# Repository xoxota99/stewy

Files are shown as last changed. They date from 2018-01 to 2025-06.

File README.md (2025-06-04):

# 6dof-stewduino

Arduino project for a 6DOF, PID-controlled Stewart platform, running on Teensy. Inspired by https://www.youtube.com/watch?v=j4OmVLc_oDw.

## Goal

Teach myself embedded development, using something a little more unique/less trivial than a typical "Blinky" app. This project incorporates:
  * Bi-directional Serial I/O (Command shell)
  * Wiimote nunchuck control (over I2C)
  * Resistive touchscreen (Analog 4-wire)
  * Multiple servos (Digital IO)

## Project Description

A ball bearing sits on the touchscreen, which reports the X/Y coordinates of the weight. The X/Y coordinates are used to generate an "error" value against the current set point, and this error is used in a PID feedback loop to control six servos. The servos drive the angle of the platform in an inverse-kinematic solution, to drive the ball bearing toward the setpoint.

## Serial Command Interface

The project includes a command-line interface over USB serial that allows you to:
  * Calibrate the touchscreen
  * Tune PID parameters
  * Change the current X/Y setpoint
  * Adjust touchscreen filtering and deadband
  * Control individual servos directly
  * Run demo sequences
  * View system information

Available commands include:
  * `help` - Display available commands
  * `set` - Set a single servo angle
  * `moveto` - Move platform to a specific position
  * `calibrate` - Start touchscreen calibration
  * `px`, `py`, `ix`, `iy`, `dx`, `dy` - Set PID parameters
  * `dump` - Display system information
  * `demo` - Run a demonstration sequence

## Touchscreen

The project uses a [4-wire resistive touchscreen](https://tinyurl.com/ybsr2pmk) and the [Adafruit Touchscreen library](https://github.com/adafruit/Touch-Screen-Library) to determine the X/Y coordinates of the ball bearing. The touchscreen driver includes:
  * Calibration routine with EEPROM storage
  * Moving average filter to reduce noise
  * Deadband filter to prevent jitter

## PID Control Loop

The project uses a Proportional/Integral/Derivative (PID) feedback loop to determine the error position between the ball bearing's current position and the setpoint position. This is used to determine the target orientation of the platform, in order to best return the ball to the setpoint position. Features include:
  * Separate PID controllers for X and Y axes
  * Configurable PID parameters via serial commands
  * Safety limits to prevent unstable behavior

## Wiimote Nunchuck Control

The project uses a Wiimote [nunchuck](https://en.wikipedia.org/wiki/Wii_Remote#Nunchuk) to change "modes" and control various aspects of the platform in real time. Mode changes are indicated by the LED blinking. The various modes can be cycled through in order by clicking the C button:

  * 1 blink: **SETPOINT** - The platform will attempt to keep the ball at a given X/Y setpoint. By default, this is in the middle of the plate. **This is the default mode at startup.** In this mode:
    * The joystick can be used to move the setpoint, with the platform correcting the position of the ball in real time.
    * Clicking the Z button (or resetting the Teensy) resets the setpoint to the middle of the plate.
  
  * 2 blinks: **CONTROL** - Direct control of the platform using the joystick. Input from the touchscreen sensor is ignored completely. In this mode:
    * Clicking the Z button cycles between three sub-modes:
      * **PITCH_ROLL** - (default) The joystick controls the pitch/roll of the platform.
      * **HEAVE_YAW** - The joystick controls the up/down and rotation of the platform.
      * **SWAY_SURGE** - The joystick controls the forward/rear and left/right translation of the platform.
  
  * 3 blinks: **CIRCLE** - *(planned)* The setpoint will move in a circular pattern, around the center of the platform.
  
  * 4 blinks: **EIGHT** - *(planned)* Similar to *CIRCLE*, the setpoint will move in a [Lemniscate of Bernoulli](https://en.wikipedia.org/wiki/Lemniscate_of_Bernoulli), centered on the center of the platform.
  
  * 5 blinks: **SQUARE** - *(planned)* The setpoint will be set to the current location of the ball on the plate.

## Project Structure

The project is organized into the following directory structure:

- `include/`: Header files
  - `core/`: Core functionality and common definitions
  - `drivers/`: Hardware driver interfaces
  - `ui/`: User interface related headers
  - `platform/`: Platform-specific code

- `src/`: Source files
  - `core/`: Core functionality implementation (Platform kinematics)
  - `drivers/`: Hardware driver implementations (TouchScreen, Nunchuck)
  - `ui/`: User interface implementations (CommandLine)
  - `platform/`: Platform-specific implementations

- `examples/`: Example applications
  - `BasicMovement/`: Basic platform movement example
  - `TouchscreenCalibration/`: Touchscreen calibration example

- `doc/`: Documentation
  - `TODO.md`: Project tasks and improvements
  - `CAD files/`: CAD designs for the platform

- `lib/`: External libraries

## Technical Details

- **Platform**: [Teensy 3.x](https://www.pjrc.com/store/teensy32.html)
- **Build System**: PlatformIO
- **Servo Control**: Direct via Arduino Servo library
- **Inverse Kinematics**: Optimized algorithm with boundary checking
- **Touchscreen**: 4-wire resistive with filtering and calibration
- **Nunchuck**: I2C communication with mode management

## Building the Project

To build the project, you can use the provided build script:

```bash
./build.sh
```

Or run PlatformIO directly:

```bash
platformio run
```

## Current Status and Future Improvements

The project currently has:
- ✅ Working inverse kinematics with optimized calculations
- ✅ Touchscreen input with filtering and calibration
- ✅ PID control for ball balancing
- ✅ Basic nunchuck control with mode switching
- ✅ Command-line interface for configuration and control
- ✅ Proper resource management and error handling

Planned improvements:
- Complete the CIRCLE, EIGHT, and SQUARE modes
- Improve mechanical design for easier assembly and lower cost
- Enhance power management to prevent brownouts
- Add unit tests and improve code portability
- Implement auto-tuning for PID controllers

See the [TODO.md](doc/TODO.md) file for a complete list of planned improvements and current status.

## Caveats

* The project is built for Teensy 3.x. Other platforms may require modifications.
* The folder structure is designed for PlatformIO and is incompatible with Arduino IDE.
* Servo control is handled directly in main.cpp rather than through a dedicated driver class.

## License

This project is licensed under the GPL-3.0 License - see the LICENSE file for details.

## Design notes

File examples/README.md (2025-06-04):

# Examples Directory

This directory contains example applications and usage demonstrations for the Stewy project. Each example focuses on a specific aspect of the system.

## Available Examples

- `BasicMovement/`: Demonstrates basic platform movement using the Platform class
  - Shows how to initialize the platform and move it to different positions
  - Includes examples of pitch, roll, and combined movements

- `TouchscreenCalibration/`: Demonstrates the touchscreen calibration process
  - Shows how to initialize and calibrate the touchscreen
  - Includes visualization of touchscreen data

## Planned Examples

The following examples are planned for future development:

- Nunchuck control demonstration
- PID tuning examples
- Mode demonstrations (CIRCLE, EIGHT, SQUARE)

## Usage

Each example is a standalone application that can be compiled and uploaded to the Teensy board. To use an example:

1. Open the example directory in PlatformIO
2. Build and upload the example to your Teensy
3. Follow the instructions in the example's comments

Note that some examples may require specific hardware components to be connected (e.g., touchscreen, nunchuck).

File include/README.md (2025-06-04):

# Include Directory

This directory contains all header files for the Stewy project. Header files are organized into subdirectories based on their functionality.

## Directory Structure

- `core/`: Core functionality and common definitions
  - `Config.h`: Project-wide configuration constants and settings
  - `Platform.h`: Stewart platform kinematics and control interface
  - `PlatformGeometry.h`: Geometric constants and calculations for the platform

- `drivers/`: Hardware driver interfaces
  - `TouchScreen.h`: Interface for the touchscreen driver with filtering and calibration
  - `Nunchuck.h`: Interface for the Wii Nunchuck controller with mode management

- `ui/`: User interface related headers
  - `CommandLine.h`: Serial command interface for controlling the platform

- `platform/`: Platform-specific code
  - `TeensyHardware.h`: Teensy-specific hardware abstractions and utilities

## Usage Guidelines

1. Use relative includes with proper paths (e.g., `#include "core/Config.h"`)
2. Keep header files minimal and focused on a single responsibility
3. Use forward declarations when possible to minimize dependencies
4. Document all public interfaces with Doxygen-style comments
5. Include appropriate copyright and license information in each file

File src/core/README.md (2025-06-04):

# Core Directory

This directory contains the core functionality of the Stewy project. These components form the foundation of the system and are not tied to specific hardware implementations.

## Contents

- `Platform.cpp`: Implementation of the Stewart platform kinematics and control
  - Implements inverse kinematics to calculate servo angles from desired platform position
  - Provides methods for moving the platform to specific positions and orientations
  - Includes boundary checking and error handling for movement parameters

## Key Features

### Inverse Kinematics

The Platform class implements an optimized inverse kinematics algorithm that:
- Calculates servo angles based on desired platform position and orientation
- Supports 6 degrees of freedom (sway, surge, heave, pitch, roll, yaw)
- Includes boundary checking to prevent impossible movements
- Optimizes trigonometric calculations for better performance
- Supports an enhanced IK algorithm with adjustable rotation point

### Platform Control

The Platform class provides methods for:
- Moving the platform to a specific position and orientation
- Moving the platform to a home position
- Simplified control of just pitch and roll
- Getting current platform state

## Architecture

The core components follow these design principles:

1. Hardware independence: Core functionality doesn't depend on specific hardware
2. Clear separation of concerns: Platform kinematics are separate from hardware control
3. Robust error handling: All methods include parameter validation and error reporting
4. Efficient implementation: Optimized calculations for embedded systems

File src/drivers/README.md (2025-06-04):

# Drivers Directory

This directory contains hardware driver implementations for the Stewy project. Each driver provides an interface to a specific hardware component.

## Contents

- `TouchScreen.cpp`: Implementation of the touchscreen driver for detecting ball position
- `Nunchuck.cpp`: Implementation of the Wii Nunchuck controller driver for user input

## Architecture

The drivers in this directory follow a consistent pattern:
- Each driver has a corresponding header file in the `include/drivers/` directory
- Drivers handle hardware initialization, data processing, and provide a clean interface to the rest of the application
- The touchscreen driver includes filtering, calibration, and PID control functionality
- The nunchuck driver handles button events, mode management, and joystick input processing

## Note on Servo Control

Servo control is handled directly in `main.cpp` using the standard Arduino Servo library rather than through a dedicated driver class. This approach was chosen because:
1. The Arduino Servo library already provides a clean interface
2. Servo control in this project is straightforward
3. Servos are tightly integrated with the Platform class's inverse kinematics

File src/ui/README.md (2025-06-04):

# UI Directory

This directory contains user interface components for the Stewy project. These components handle user input and provide feedback to the user.

## Contents

- `CommandLine.cpp`: Implementation of the command-line interface
  - Processes commands from the serial interface
  - Provides a set of commands for controlling and configuring the platform
  - Uses the GeekFactory Shell Library for command parsing and execution

## Features

The command-line interface provides the following functionality:

- Direct servo control (`set`, `mset`, `setall`, `msetall`)
- Platform movement control (`moveto`, `home`)
- System information display (`dump`)
- PID controller tuning (`px`, `py`, `ix`, `iy`, `dx`, `dy`)
- Touchscreen calibration (`calibrate`)
- Log level control (`log`)
- Demo sequence execution (`demo`)
- System reset (`reset`)

## Architecture

The UI components follow these design principles:

1. Separation of concerns: UI components don't directly control hardware
2. Command handlers are implemented as static methods
3. The UI maintains references to other components (touchscreen, nunchuck) but doesn't own them
4. Error handling includes parameter validation and user feedback

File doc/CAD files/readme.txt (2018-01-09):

The layout for base_bottom and base_top are designed for the Hitec HS-5625MG servo.

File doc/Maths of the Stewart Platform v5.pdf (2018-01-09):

## The Mathematics of the Stewart Platform

The Stewart Platform consists of 2 rigid frames connected by 6 variable length legs.

The Base is considered to be the reference frame work, with orthogonal axes x, y, z.

The Platform has its own orthogonal coordinates x’, y’, z’.

The Platform has 6 degrees of freedom with respect to the Base

The origin of the Platform coordinates can be defined by 3 translational displacements with respect to the Base, one for each axis.

Three angular displacements then define the orientation of the platform with respect to the Base. A set of Euler angles are used in the following sequence:

1. Rotate an angle ψ (yaw) around the z-axis
2. Rotate an angle θ (pitch) around the y-axis
3. Rotate an angle (roll) around the x-axis

If we consider the first rotation ψ (yaw) around the z-axis:

P = i’x’ + j’y’ + k’z’ = ix + jy + kz

x = OA – BC

= x’cos ψ – y’sin ψ

y = AB + PC

= x’sin ψ + y’cos ψ

z = z’

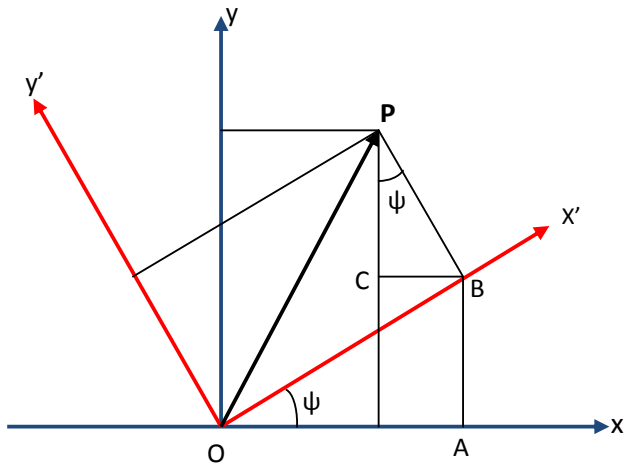
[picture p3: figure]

We define the rotation matrix | where

=

and | =

Similarly If we consider the second rotation θ (pitch) around the y-axis we can show

=

,

And for the third rotation (roll) around the x-axis:

=

The full rotation matrix of the Platform relative to the Base is then given by:

=

=

=

=

- (1)

Now consider a Stewart Platform.

For the

leg:

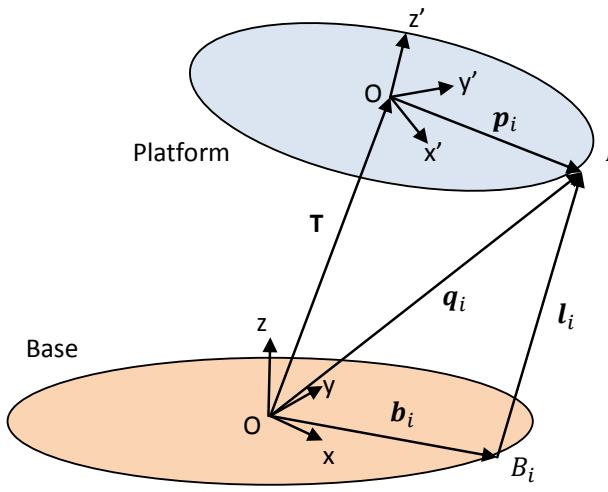
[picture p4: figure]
Platform; Base

The coordinates | of the anchor point | with respect to the Base reference framework are
given by the equation

= T +

- (2)

Where T is the translation vector, giving the positional linear displacement of the origin of the Platform frame with respect to the Base reference framework, and

is the vector defining the coordinates of the anchor point with respect to the Platform framework.

Similarly the length of the

leg is given by

| = T +

- (3)
| where is the vector
defining the coordinates of the lower anchor point
| . These 6 equations give the lengths
of the 6 legs to achieve the desired position and attitude of the platform.

When considering the Forward Kinematics, this expression represents 18 simultaneous non-linear equations in the 6 unknowns representing the position and attitude of the platform. Much work has been done on finding the solutions to these equations; in the general case there are 40 possible solutions, although in practice many of these solutions would not be practical.

If the leg lengths are achieved via rotational servos, rather than linear servos, a further calculation is required to determine the angle of rotation of the servo. Each servo / leg combination can be represented as follows:

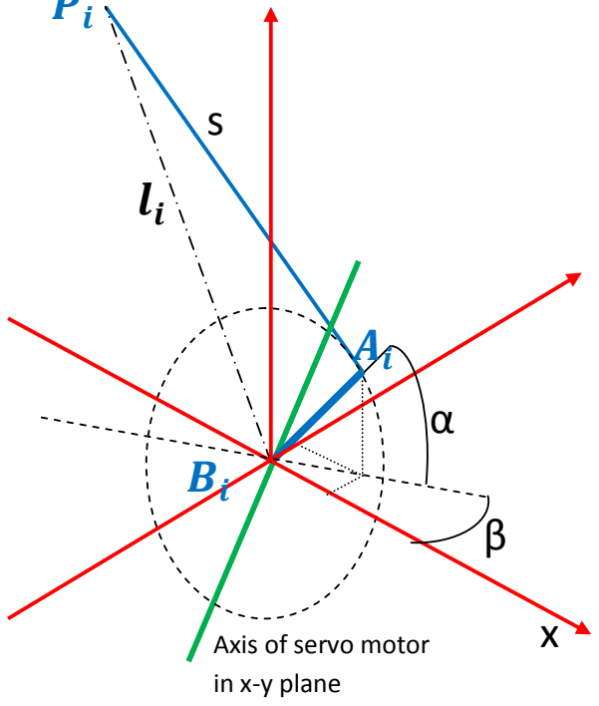
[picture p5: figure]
Axis of servo motor in x-y plane

y

z

Where: a = length of the servo operating arm

are the points of the arm/leg joint on the

servo with coordinates

=

in the base framework.

are the points of rotation of the servo arms with the coordinates

=

in the base framework.

are the points the joints between the operating rods and the platform,

with coordinates | =

in the platform framework

S = length of operating leg

= length of the
leg as calculated from

= T +

α = angle of servo operating arm from horizontal

β = angle of servo arm plane relative to the x-axis. Note that the shaft axis lies in the x-y plane where z = 0

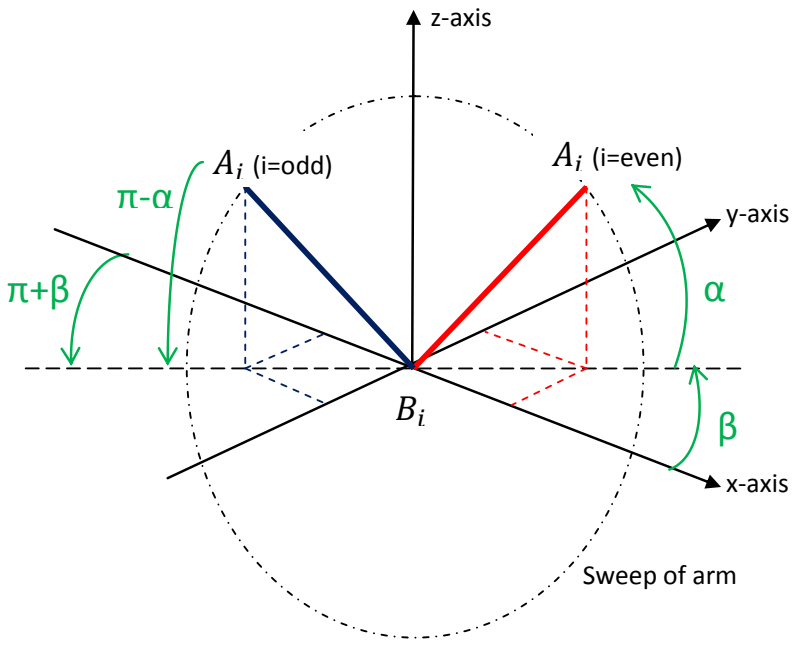
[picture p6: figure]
z-axis; y-axis; x-axis; Sweep of arm; (i=even); (i=odd)

Point is constrained to be on the servo arm, but the arrangement of the servos means that the odd and even arms are a reflection of each other. So for the even legs we have:

= a | , and | - (4)
= a | , and | - (5)

= a | - (6)

And for the odd legs we have:

= a | , and
= a | , and

= a

But | = | , and | =
And | = | , and | =

Substituting these values into the equations for the odd legs, we get the same equations as (4), (5), and (6) for the even legs.

By Pythagoras we also have:

=

+

+

=

+

- 2
- (7)

=

+

+

=

+

- 2 | - (8)

=

+

+

=

+

- 2

And substituting from equations (7) & (8)

=

+ 2 | +

+
2
- 2

re-arranging gives

= 2

+ 2 | + 2 | + 2 | –
2
And substituting for | , | , | from equations (4), (5) & (6) then gives

= 2

+ 2

+
2

+ 2

2

= 2

+ 2 | + 2 | - 2

+
2a | + 2 | - 2
+ 2a | + 2 | -
2

Which reduces to

= 2a | 2 | + 2a
= 2a | 2a

Which is an equation of the form:-

L =

Using the Trig identity for the sum of sine waves

where

and

We therefore have another sine function of α with a phase shift δ

L = | where | δ =
Therefore | =
And | α =

- (9)

where L =

M = 2a

N = 2a

We now have sufficient information to calculate the lengths of the effective “legs”, and the associated angle of the servo arms, for the reverse kinematics for the platform. But to design and implement the hexapod platform we need to define a few constants in order to define the range of movement.

1) We need to define the “home” position of the platform. By definition this will be where the platform is at a height above the base framework, and there being no other translational or rotational movement.

i.e.

= T +

=

=

Similarly we will define the “home” position where the servo arms and rods are at right angles to each other.

i.e.

=

Giving

- (10)

and since the platform is constructed symmetrically around the z-axis, this equation will give the same result for any leg.

2) We can also calculate the angle of the servo arm at the Home position.

Using the equation

= T +

And remembering the symmetrical construction of the platform. The length of the legs in the “home” position is given by

- (11)

And the angle of the servo arm in the “home” position can be given by equation (9). Since we have symmetry, we can look at leg 2 only, where β = 0°.

=

- (12)

where =

= 2

| = 2a
| = 2a
| = 2a

The servos are mounted so that their mid point is close to the “home” position, and we will restrict their movement to ± 45°. The servos are controlled by a pulse whose duration defines the angle of the arm.

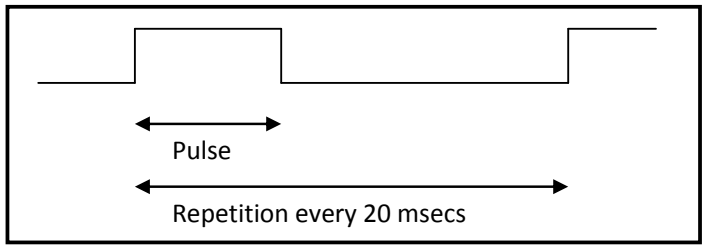
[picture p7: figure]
Pulse; Repetition every 20 msecs

The servos used have the specification:

Neutral position (“home”) is nominally 1500µsecs

Rotation clockwise for increasing pulse width

Pulse width change for 45° is 400 µsecs giving a servo rate,

r =

=

µsecs / radian

From the above, the pulse widths

for each of the servos can be obtained by the equations:

for even i and | -(13)
for odd i | - (14)

Where

is the actual pulse width required to hold the | servo in the “home”
position. This is nominally 1500µsecs, but can be adjusted to compensate for differences in actual assembly.

## Controlling the Stewart Platform using RC Servos

The platform is constructed with symmetry round the z-axes, but the odd and even servos are mounted in opposition.

The circuitry used to control the platform is based on a PICAXE microcontroller with attached maths co-processor (floating point) and attached servo motor controller.

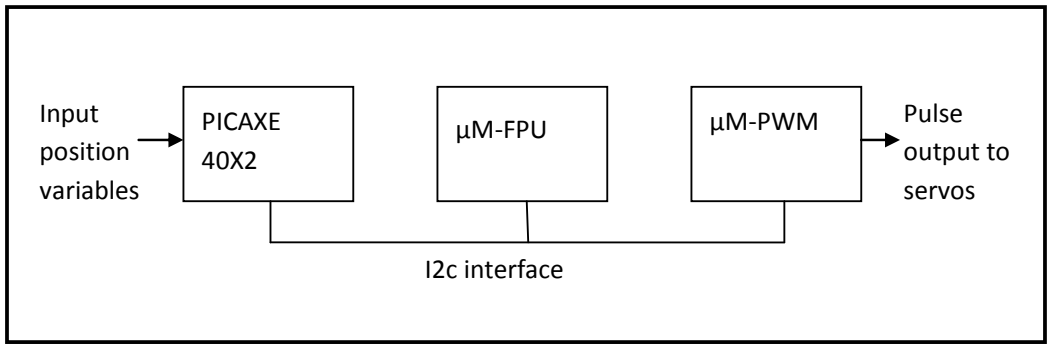
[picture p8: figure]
PICAXE 40X2; µM-FPU; µM-PWM; I2c interface; Input position variables; Pulse output to servos

The sequence of events is as follows:

1) Input the positional information for the platform,

s, a,

. These are all
constants from the build of the platform.
2) Input the constants for the servo motors,

and r
3) Calculate the values of | from equation (10), and | from equation (12)
4) Input the variables for (x, y, z, ψ, θ, φ) for the required platform position
5) Calculate the rotational matrix

from equation (1)
6) Calculate the effective leg lengths
from equations (3)
7) Calculate the angles

required for each servo from equation (9)
8) Calculate the pulse widths

required for each servo from equations (13) & (14)
9) Output the values of

to the µM-PWM to drive the servos
10) Return to step 4) to repeat the process.

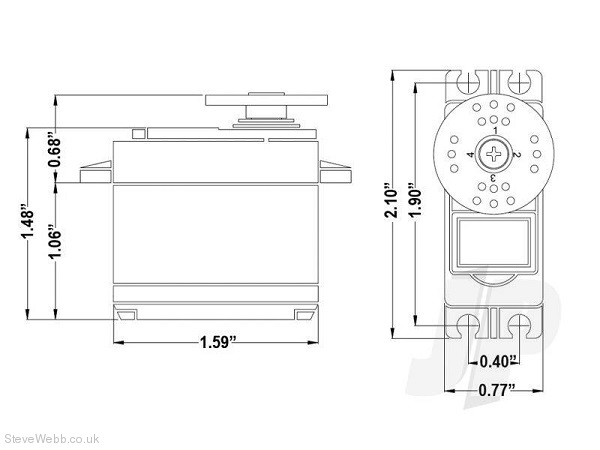
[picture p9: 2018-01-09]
doc/hitec-hs5625d_a.jpg

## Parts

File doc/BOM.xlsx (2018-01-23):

Part | Qty | Unit cost | Total cost | Link
Hitec RCD HS-5625MG Digital High Speed Metal Gear Servo | 6 | $39.00 | $234.00 | https://www.amazon.com/dp/B0006O3XKO
Laser-cut acrylic parts | 1 | $69.00 | $69.00 | https://www.ponoko.com/design-your-own/products/stewduino-clear-14641
4-Wire resistive touchscreen, 12.1" | 1 | $66.57 | $66.57 | https://www.digikey.com/product-detail/en/nkk-switches/FTAS00-12.1AN-4/360-3520-ND/6823699
Teensy 3.2 | 1 | $24.44 | $24.44 | https://www.amazon.com/dp/B015M3K5NG
BEC / regulator | 1 | $19.99 | $19.99 | https://www.amazon.com/dp/B000MXAR12
Turnigy nano-tech 2000mAh 2S1P 20~40C Lipo Receiver Pack | 1 | $12.47 | $12.47 | https://hobbyking.com/en_us/turnigy-nano-tech-2000mah-2s1p-20-40c-lipo-receiver-pack.html
Servo power board | 1 | $9.99 | $9.99 | https://www.amazon.com/dp/B019EH6HYW
control rod ends (6-pack) | 1 | $8.98 | $8.98 | https://www.amazon.com/dp/B075J9WJR7
control rods (20-pack) | 1 | $8.55 | $8.55 | https://www.amazon.com/dp/B00OK6DT76
mounting tape | 1 | $4.49 | $4.49 | https://www.amazon.com/dp/B004E3PMKM
Hardware: M3x10 button-head hex screws | 10 |  | $0.00 | https://www.mcmaster.com/#91239a115
Hardware: M3x12 button-head hex screws | 6 |  | $0.00 | https://www.mcmaster.com/#91239a117
Hardware: M3x16 Counter-sunk hex screws | 4 |  | $0.00 | https://www.mcmaster.com/#91239a120
Hardware: M2x6 socket-head hex screws | 4 |  | $0.00 | https://www.mcmaster.com/#91290a013
0.25" double-sided tape | 1 | $7.99 | $7.99 | https://www.amazon.com/dp/B01MYUFTQO
Tools required:
 | Soldering Iron
 | 1.5mm hex driver |  |  | https://www.amazon.com/dp/B00OCO9178
 | 2.0mm hex driver |  |  | https://www.amazon.com/dp/B00OCO9178
 | drill
 | M2 tapping bit |  |  | https://www.amazon.com/dp/B078H9MTHW
 | countersink bit |  |  | https://www.amazon.com/dp/B01G84OJLC
 | M3 cutting die |  |  | https://www.amazon.com/dp/B005CL47A6
 | hookup wire |  |  | https://www.amazon.com/dp/B008MOLG04
* Note: Links are provided for convenience only. I do not endorse any of these products. Use at own risk.

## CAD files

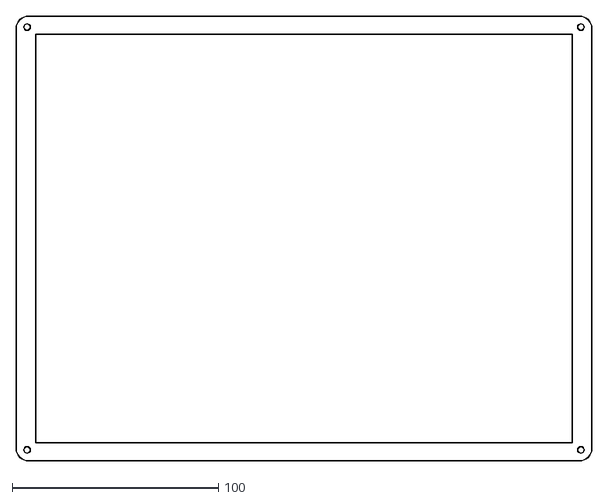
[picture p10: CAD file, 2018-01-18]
doc/CAD files/DXF/ts_platform_over.dxf
279.4 x 215.9

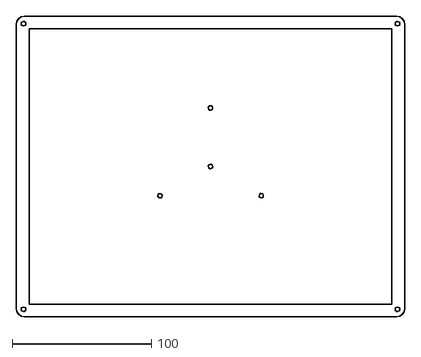
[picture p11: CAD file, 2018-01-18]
doc/CAD files/DXF/ts_platform_under.dxf
279.4 x 215.9

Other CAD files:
doc/CAD files/DXF/base_top.dxf
doc/CAD files/DXF/platform_large.dxf
doc/CAD files/DXF/base_bottom.dxf
doc/CAD files/DXF/platform_small.dxf

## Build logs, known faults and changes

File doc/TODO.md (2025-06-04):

# Stewy Project TODO List

This document tracks improvements and tasks for the Stewy project. Check off items as they are completed.

## 1. Code Quality Improvements

- [x] Add Documentation:
  - [x] Add basic Doxygen-style documentation to class and function headers
  - [x] Complete documentation for all functions with parameters, return values, and behavior

- [ ] Implement Unit Tests:
  - [ ] Create a testing framework for the platform's inverse kinematics
  - [ ] Add tests for the PID controller functionality
  - [ ] Test edge cases for servo movement limits

- [ ] Code Organization:
  - [x] Organize code into proper directory structure with include/ and src/ folders
  - [ ] Further refactor main.cpp into smaller, more focused modules
  - [ ] Create separate classes for different functionalities (e.g., ServoController)

- [ ] Error Handling:
  - [ ] Add more robust error handling throughout the codebase
  - [ ] Implement a proper error reporting system instead of just logging

- [ ] Configuration Management:
  - [x] Use EEPROM to store calibration values
  - [ ] Move more hardcoded values from config.h to a configuration file that can be loaded at runtime

## 2. Feature Implementations

- [ ] Complete Planned Features:
  - [ ] Implement the "coming soon" features mentioned in the README:
    - [ ] CIRCLE mode
    - [ ] EIGHT mode
    - [ ] SQUARE mode
  - [ ] Add the ability to save and load different configurations

- [x] Calibration Improvements:
  - [x] Create an automated calibration routine for the touchscreen
  - [ ] Implement a servo calibration procedure to fine-tune the SERVO_TRIM values

- [ ] User Interface:
  - [x] Implement basic command line interface
  - [ ] Develop a more user-friendly serial command interface
  - [ ] Add a web interface using ESP8266/ESP32 for remote control and monitoring

## 3. Hardware Design Improvements

- [ ] Power Management:
  - [ ] Implement the power management improvements mentioned in the README
  - [ ] Add detection for USB vs. battery power and adjust servo behavior accordingly
  - [ ] Consider adding a separate power supply for the servos

- [ ] Mechanical Design:
  - [ ] Redesign the platform to use a single thickness of material as suggested in the README
  - [ ] Break up the upper ring into smaller pieces for more cost-effective manufacturing
  - [ ] Design a more universal mounting system for different servo types

## 4. Performance Optimizations

- [ ] PID Controller Tuning:
  - [x] Implement configurable PID parameters
  - [ ] Implement auto-tuning for the PID controllers
  - [ ] Add more sophisticated filtering for the touchscreen input

- [x] Inverse Kinematics:
  - [x] Optimize the IK algorithm as mentioned in the README
  - [x] Implement the mathematical improvements for better range of movement
  - [x] Add boundary checking for all movement parameters

- [ ] Memory Usage:
  - [ ] Optimize memory usage, especially for the Teensy platform
  - [ ] Consider using fixed-point math instead of floating-point for performance

## 5. Build and Deployment

- [ ] Cross-Platform Compatibility:
  - [ ] Make the code more portable across different Arduino platforms
  - [ ] Replace Teensy-specific code (like Serial.printf) with more portable alternatives

- [ ] Continuous Integration:
  - [x] Add basic Travis CI configuration
  - [ ] Set up a proper CI/CD pipeline with automated testing

- [ ] Documentation:
  - [ ] Create better user documentation with setup instructions
  - [ ] Add diagrams and illustrations for assembly

## 6. Specific Technical Improvements

- [x] Platform.cpp:
  - [x] Optimize the inverse kinematics calculations
  - [x] Add boundary checking for all movement parameters
  - [x] Implement enhanced IK algorithm with adjustable rotation point

- [x] Touchscreen Handling:
  - [x] Implement filtering for the touchscreen input
  - [x] Add calibration routines for the touchscreen
  - [x] Implement deadzone filter to avoid jitter

- [ ] Servo Control:
  - [x] Add acceleration/deceleration to servo movements for smoother operation
  - [ ] Implement a safety system to prevent servo overheating

- [x] Nunchuck Interface:
  - [x] Implement basic mode switching and control
  - [ ] Improve the responsiveness of the nunchuck controls
  - [ ] Complete implementation of all planned modes

## 7. Logical Errors to Fix

- [x] **PID Controller Input/Output Handling**
  - [x] Review how PID values are updated and ensure proper input/output flow
  - [x] Add validation for PID parameters to prevent unstable behavior

- [x] **Touchscreen Calibration Persistence**
  - [x] Store calibration data in EEPROM
  - [x] Add validation for EEPROM calibration data
  - [x] Implement fallback defaults if calibration data is corrupted

- [ ] **Error Handling for Missing Hardware**
  - [x] Add detection for nunchuck connection
  - [ ] Implement more graceful handling for connected but non-responsive hardware
  - [ ] Implement timeout mechanisms for hardware communication

- [x] **Resource Management**
  - [x] Add proper cleanup for objects created with `new`
  - [ ] Consider using smart pointers or RAII patterns for better resource management

- [ ] **Concurrent Access to Servo Values**
  - [ ] Implement a synchronization mechanism for the servoValues array
  - [ ] Create a priority system for different components updating servo positions

- [x] **Timing Issues**
  - [x] Add timing control to the main loop for consistent execution
  - [x] Ensure PID loops run at consistent intervals for proper control

- [ ] **Initialization Order Dependencies**
  - [x] Implement proper initialization sequence
  - [ ] Add more explicit checks to ensure components are initialized before use

- [ ] **Lack of Bounds Checking**
  - [x] Add bounds checking for platform movement parameters
  - [ ] Add explicit bounds checking for all array accesses
  - [ ] Implement safe accessor methods for critical data structures

- [ ] **Incomplete Implementation of Planned Features**
  - [ ] Complete or disable advertised features that aren't fully implemented
  - [ ] Add clear status indicators for features in development

- [ ] **Potential Floating Point Precision Issues**
  - [x] Optimize floating point calculations in inverse kinematics
  - [ ] Consider fixed-point alternatives for critical calculations

- [ ] **Inconsistent Error Handling**
  - [ ] Standardize error handling approach across the codebase
  - [ ] Ensure all return values are properly checked

- [ ] **Potential for Servo Binding**
  - [ ] Implement protection against servo binding conditions
  - [ ] Add current monitoring if hardware supports it
  - [ ] Create safe recovery procedures for high-current states

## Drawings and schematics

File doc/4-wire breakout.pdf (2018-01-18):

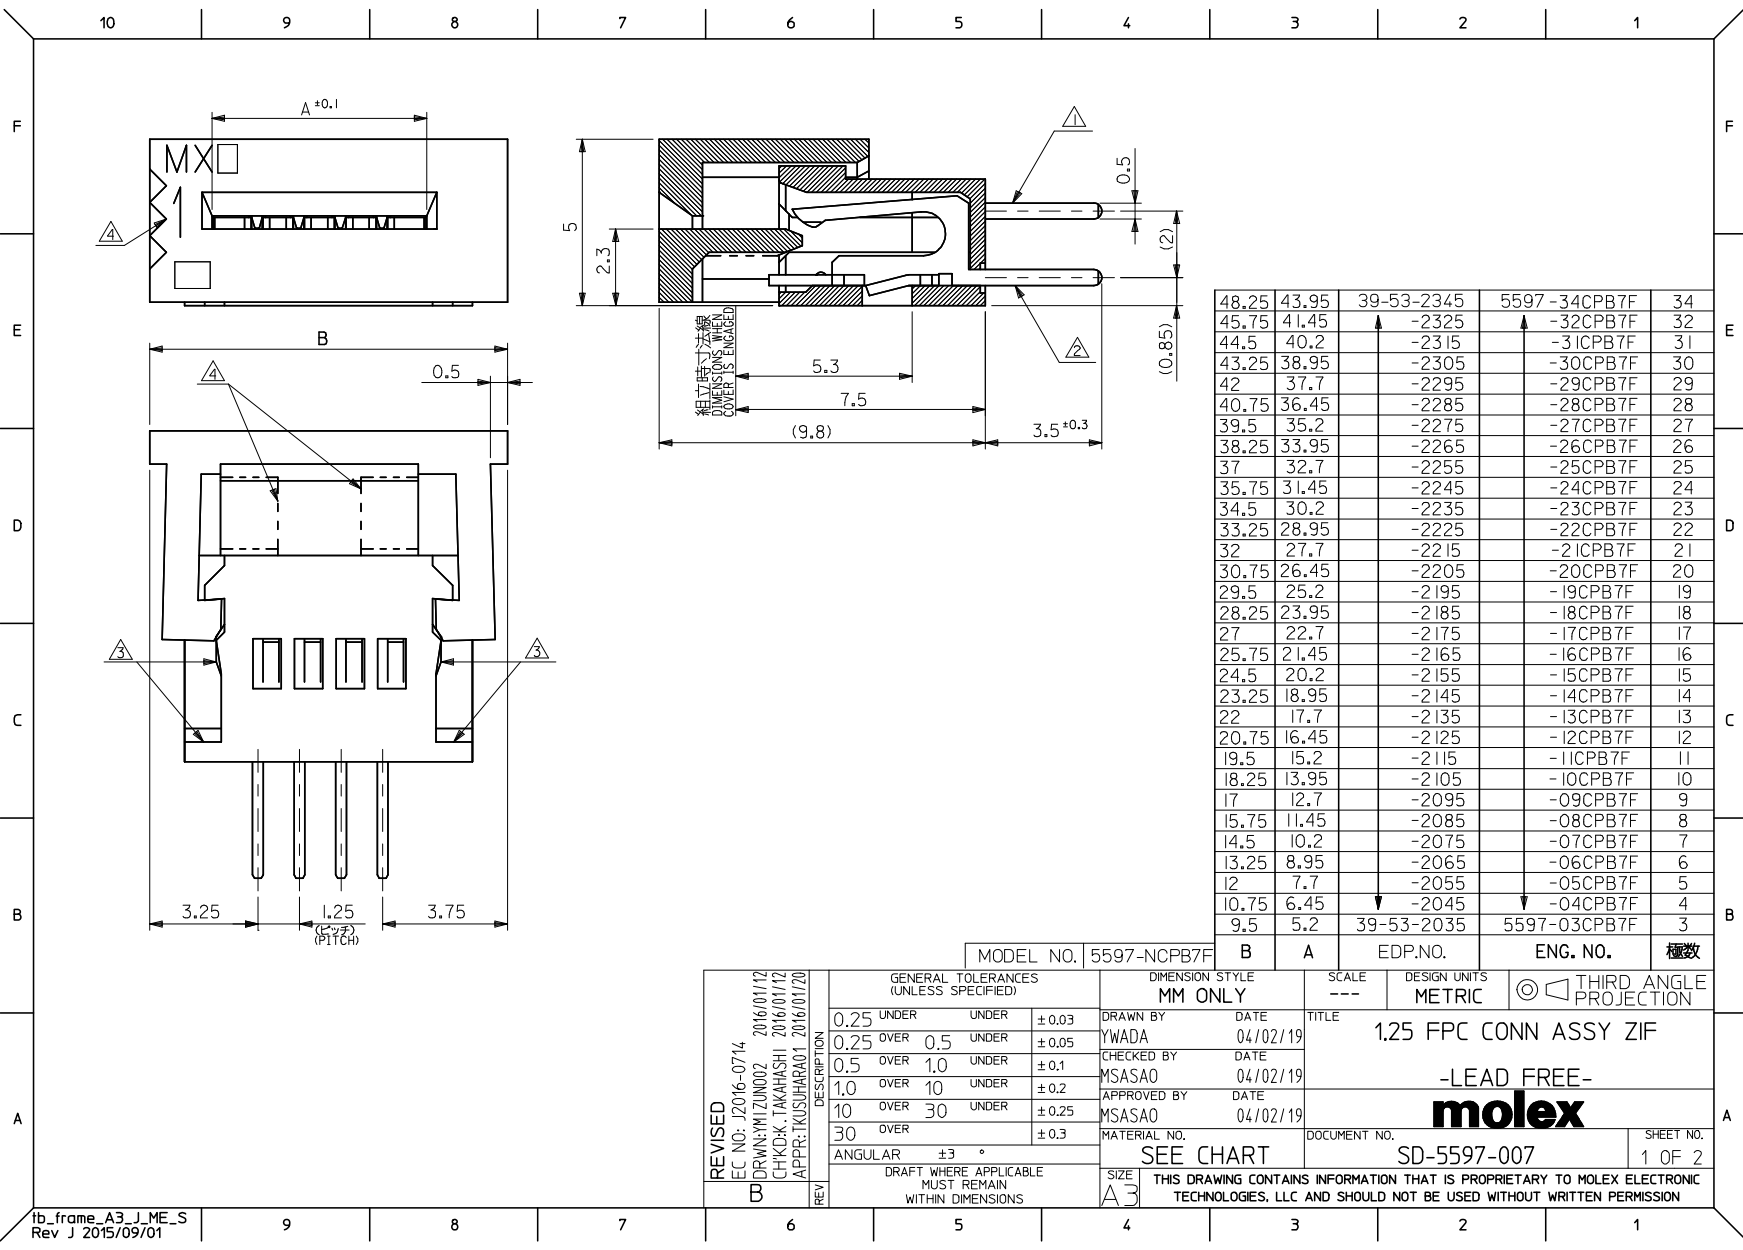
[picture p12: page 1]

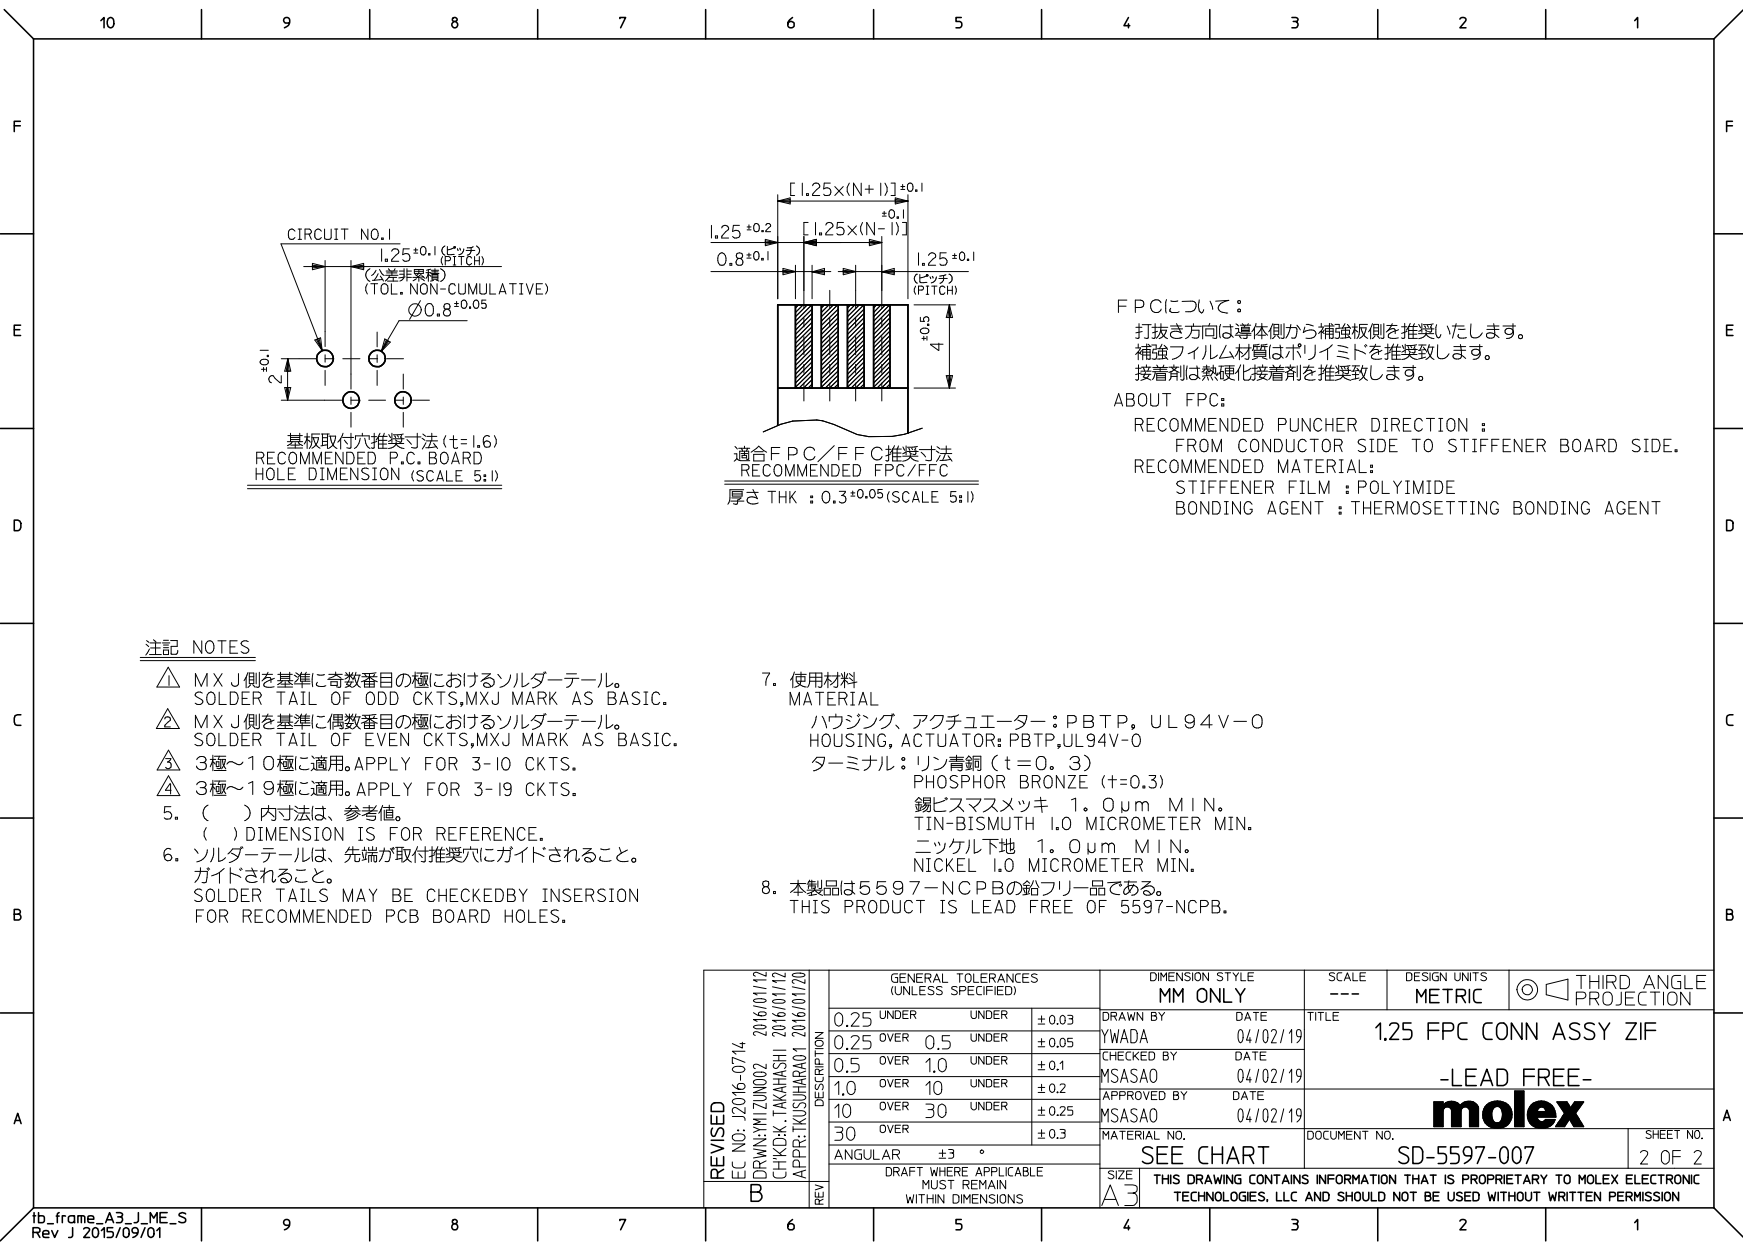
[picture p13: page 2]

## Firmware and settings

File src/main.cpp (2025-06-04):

/**
 * @file main.cpp
 * @brief Main entry point for the Stewart platform project
 *
 * This file contains the setup and loop functions required by Arduino/Teensy.
 *
 * @author Philippe Desrosiers
 * @copyright Copyright (C) 2018 Philippe Desrosiers
 * @license GPL-3.0
 *
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
 * You should have received a copy of the GNU General Public License
 * along with this program.  If not, see <https://www.gnu.org/licenses/>.
 */

#include <Arduino.h>
#include <ArduinoLog.h>
#include <Servo.h>
#include "core/Config.h"
#include "core/Platform.h"
#ifdef ENABLE_TOUCHSCREEN
#include "drivers/TouchScreen.h"
#endif

#ifdef ENABLE_NUNCHUCK
#include "drivers/Nunchuck.h"
#endif

#ifdef ENABLE_SERIAL_COMMANDS
#include "ui/CommandLine.h"
#endif

// this is the magic trick for printf to support float
asm(".global _printf_float");
// this is the magic trick for scanf to support float
asm(".global _scanf_float");

// Define the namespace for the Stewart platform
using namespace stewy;

// Create platform object
core::Platform *platform;

#ifdef ENABLE_SERVOS
// Create servo objects
Servo servos[6];
#endif

// Servo setpoints in degrees
float servoValues[6];

// Current actual servo positions (for acceleration/deceleration)
float currentServoPositions[6];

// Current servo velocities (for acceleration/deceleration)
float servoVelocities[6];

// Create driver objects
drivers::TouchScreenDriver *touchscreen;
drivers::NunchuckDriver *nunchuck;

// Create UI objects
ui::CommandLine *commandLine;

// Function to convert angle to microseconds
float toMicroseconds(int angle)
{
  return map(angle, SERVO_MIN_ANGLE, SERVO_MAX_ANGLE, SERVO_MIN_US, SERVO_MAX_US);
}

// Update servo positions
void updateServos()
{
  for (int i = 0; i < 6; i++)
  {
    float targetPosition = servoValues[i];
    float currentPosition = currentServoPositions[i];

#ifdef SERVO_ACCELERATION_ENABLED

    // Calculate the distance to the target
    float distance = targetPosition - currentPosition;

    if (abs(distance) > 0.01f) // Small threshold to avoid tiny movements
    {
      // Determine the direction of movement
      float direction = (distance > 0) ? 1.0f : -1.0f;

      // Calculate the desired velocity based on distance
      float desiredVelocity = direction * min(abs(distance), SERVO_MAX_SPEED);

      // Apply acceleration/deceleration
      if (servoVelocities[i] < desiredVelocity)
      {
        // Accelerate
        servoVelocities[i] = min(servoVelocities[i] + SERVO_ACCELERATION, desiredVelocity);
      }
      else if (servoVelocities[i] > desiredVelocity)
      {
        // Decelerate
        servoVelocities[i] = max(servoVelocities[i] - SERVO_ACCELERATION, desiredVelocity);
      }

      // Apply velocity to position
      currentPosition += servoVelocities[i];

      // Check if we've reached or overshot the target
      if ((direction > 0 && currentPosition >= targetPosition) ||
          (direction < 0 && currentPosition <= targetPosition))
      {
        currentPosition = targetPosition;
        servoVelocities[i] = 0;
      }
    }
    else
    {
      // We're at the target, ensure velocity is zero
      servoVelocities[i] = 0;
    }

    // Update the current position
    currentServoPositions[i] = currentPosition;
#else

    // No acceleration/deceleration, just use the target position
    currentPosition = targetPosition;
    currentServoPositions[i] = currentPosition;
#endif // SERVO_ACCELERATION_ENABLED

    // Apply reverse if needed
    float val = currentPosition;
    if (core::SERVO_REVERSE[i])
    {
      val = SERVO_MIN_ANGLE + (SERVO_MAX_ANGLE - val);
    }

    // Convert to microseconds and apply trim
    val = toMicroseconds(val) + core::SERVO_TRIM[i];

// Write to servo
#ifdef ENABLE_SERVOS
    servos[i].writeMicroseconds(constrain(val, SERVO_MIN_US, SERVO_MAX_US));
#endif
  }
}

void setup()
{
  // Initialize serial communication
  Serial.begin(115200);
  delay(100);

  Log.begin(LOG_LEVEL, &Serial);
  Log.info("Stewy Platform Starting...");
  Log.info("Built %s, %s", __DATE__, __TIME__);

  // Initialize platform
  platform = new core::Platform(SERVO_MIN_ANGLE, SERVO_MAX_ANGLE);

  // Initialize servo position and velocity arrays
  for (int i = 0; i < 6; i++)
  {
    currentServoPositions[i] = core::SERVO_MID_ANGLE;
    servoVelocities[i] = 0.0f;
  }

// Initialize servos
#ifdef ENABLE_SERVOS
  Log.info("Initializing servos...");
  for (int i = 0; i < 6; i++)
  {
    servos[i].attach(core::SERVO_PINS[i]);
  }
#else
  Log.info("Servo control is DISABLED");
#endif

// Initialize touchscreen
#ifdef ENABLE_TOUCHSCREEN
  Log.info("Initializing touchscreen...");
  touchscreen = new drivers::TouchScreenDriver(XP, YP, XM, YM, TS_OHMS);
  touchscreen->init();
#else
  Log.info("Touchscreen support is DISABLED");
#endif

// Initialize nunchuck
#ifdef ENABLE_NUNCHUCK
  Log.info("Initializing nunchuck...");
  nunchuck = new drivers::NunchuckDriver();
  nunchuck->init();
#else
  Log.info("Nunchuck support is DISABLED");
#endif

// Initialize command line
#ifdef ENABLE_SERIAL_COMMANDS
  Log.info("Initializing command line interface...");
  commandLine = new ui::CommandLine(touchscreen, nunchuck, servoValues);
  commandLine->init();
#else
  Log.info("Command line interface is DISABLED");
#endif

  // Do a litlle initialization sequence
  Log.info("Sweeping servos to ensure they are working...");
  for (int pos = SERVO_MIN_ANGLE; pos < core::SERVO_MID_ANGLE; pos += 4)
  {
    for (int i = 0; i < 6; i++)
    {
      servoValues[i] = pos;
    }

    updateServos();
    delay(10);
  }

  // Move to home position
  platform->home(servoValues);
  updateServos();

  Log.info("Initialization complete");
}

void loop()
{
  // Record the start time of this loop iteration
  unsigned long loopStartTime = millis();

// Process command line
#ifdef ENABLE_SERIAL_COMMANDS
  commandLine->process();
#endif

// Process nunchuck input
#ifdef ENABLE_NUNCHUCK
  core::xy_coordf setpoint = nunchuck->process(servoValues);

  // Process the Blinker to handle LED blinking
  stewy::drivers::modeBlinker.loop();
#else
  core::xy_coordf setpoint = core::DEFAULT_SETPOINT;
#endif

// Process touchscreen
#ifdef ENABLE_TOUCHSCREEN
  touchscreen->process(setpoint.x, setpoint.y, servoValues);
#endif

  // Update servos
  updateServos();

  // Calculate how long this iteration took
  unsigned long loopDuration = millis() - loopStartTime;

  // If we completed faster than our target interval, delay the remaining time
  if (loopDuration < MAIN_LOOP_INTERVAL_MS)
  {
    delay(MAIN_LOOP_INTERVAL_MS - loopDuration);
  }
  else if (loopDuration > MAIN_LOOP_INTERVAL_MS)
  {
    // Log a warning if we're exceeding our target loop time
    Log.trace("Loop time exceeded target: %lu ms (target: %d ms)", loopDuration, MAIN_LOOP_INTERVAL_MS);
  }
}

// Clean up function to be called when the program exits
// This is not normally called in Arduino/Teensy, but we include it for completeness
void cleanup()
{
  // Clean up dynamically allocated objects
  if (platform != nullptr)
  {
    delete platform;
    platform = nullptr;
  }

#ifdef ENABLE_TOUCHSCREEN
  if (touchscreen != nullptr)
  {
    delete touchscreen;
    touchscreen = nullptr;
  }
#endif

#ifdef ENABLE_NUNCHUCK
  if (nunchuck != nullptr)
  {
    delete nunchuck;
    nunchuck = nullptr;
  }
#endif

#ifdef ENABLE_SERIAL_COMMANDS
  if (commandLine != nullptr)
  {
    delete commandLine;
    commandLine = nullptr;
  }
#endif

  Log.info("Cleanup complete");
}

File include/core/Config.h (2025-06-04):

#pragma once
/**
 * @file Config.h
 * @brief Global configuration settings
 *
 * This file contains global configuration settings for the Stewart platform.
 *
 * @author Philippe Desrosiers
 * @copyright Copyright (C) 2018 Philippe Desrosiers
 * @license GPL-3.0
 *
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
 * You should have received a copy of the GNU General Public License
 * along with this program.  If not, see <https://www.gnu.org/licenses/>.
 */

#include <ArduinoLog.h>

namespace stewy
{
  namespace core
  {

// Feature enable/disable flags
#define ENABLE_SERIAL_COMMANDS // Comment out, to omit Command shell code
#define ENABLE_NUNCHUCK        // Comment out, to omit Nunchuck code
#define ENABLE_TOUCHSCREEN     // Comment out, to omit Touchscreen code

/*
  Comment out, to disable Servos. Servos can get hot if you don't set
  them to a "safe" value. Commenting this line out allows to test things that
  are not servo-related, without killing the battery, browning out the USB,
  or overheating the servos.
*/
#define ENABLE_SERVOS

// LED configuration
#define LED_PIN LED_BUILTIN // LED pin for status indication

// Logging configuration
#define LOG_LEVEL LOG_LEVEL_TRACE

// Main loop timing configuration
#define MAIN_LOOP_INTERVAL_MS 20 // Target time in milliseconds for each main loop iteration

// Servo movement configuration
#define SERVO_ACCELERATION_ENABLED // Enable/disable servo acceleration/deceleration
#define SERVO_MAX_SPEED 10.0f      // Maximum speed in degrees per loop iteration
#define SERVO_ACCELERATION 0.3f    // Acceleration/deceleration rate in degrees per loop iteration squared

// Servo configuration
#define SERVO_MIN_ANGLE 0
#define SERVO_MAX_ANGLE 360
    const int SERVO_MID_ANGLE = SERVO_MIN_ANGLE + (SERVO_MAX_ANGLE - SERVO_MIN_ANGLE) / 2;

#define SERVO_MIN_US 755
#define SERVO_MAX_US 2250

    const int SERVO_MID_US = SERVO_MIN_US + (SERVO_MAX_US - SERVO_MIN_US) / 2;

    // Which servos are reversed. 1 = reversed, 0 = normal.
    const int SERVO_REVERSE[6] = {0, 1, 0, 1, 0, 1};

    // Servo trim values, in microseconds, AFTER reversing
    const int SERVO_TRIM[] = {0, 20, 0, 135, 0, 120};

    // Servo pin assignments
    const int SERVO_PINS[] = {0, 1, 2, 3, 4, 5};

// Touchscreen configuration
#ifdef ENABLE_TOUCHSCREEN
#define XP A7       // YELLOW / XRT. can be a digital pin.
#define XM A6       // WHITE / XLE. must be an analog pin, use "An" notation!
#define YP A8       // RED / YLO. must be an analog pin, use "An" notation!
#define YM A9       // BLACK / YUP. can be a digital pin.
#define TS_OHMS 711 // resistance between X+ and X-

// Default Min / max values of X and Y (will be overridden by calibration)
#define TS_DEFAULT_MIN_X 1
#define TS_DEFAULT_MAX_X 950
#define TS_DEFAULT_MIN_Y 100
#define TS_DEFAULT_MAX_Y 930

// EEPROM address for storing touchscreen calibration data
#define TOUCH_CALIBRATION_ADDR 0

// Touchscreen filtering
#define TOUCH_FILTER_SAMPLES 5  // Number of samples to use in moving average filter
#define TOUCH_FILTER_WEIGHT 0.7 // Weight for exponential filter (0-1, higher = more smoothing)
#define TOUCH_DEADZONE 5        // Deadzone to ignore small movements (in raw ADC units)

// Calibration process
#define CALIBRATION_POINTS 4   // Number of points to use for calibration
#define CALIBRATION_DELAY 2000 // Delay between calibration points in ms
#define CALIBRATION_SAMPLES 10 // Number of samples to average for each calibration point

// Time (in millis) between the touch sensor "losing" the ball, and the platform
// getting a signal to go to the "home" position.
#define LOST_BALL_TIMEOUT 250

// PID configuration
#define ROLL_PID_SAMPLE_TIME 10
#define ROLL_PID_LIMIT_MIN -1024
#define ROLL_PID_LIMIT_MAX 1024

#define PITCH_PID_SAMPLE_TIME 10
#define PITCH_PID_LIMIT_MIN -1024
#define PITCH_PID_LIMIT_MAX 1024
#endif // ENABLE_TOUCHSCREEN

// Nunchuck configuration
#ifdef ENABLE_NUNCHUCK
// Delay between movements of the Setpoint, in SQUARE mode.
#define SQUARE_DELAY_MS 1000

// Specifies the maximum time between button clicks that are interpreted as a
// double-click. If the time between clicks exceeds this value, the clicks are
// interpreted as single clicks.
#define NUNCHUCK_DBLCLICK_THRESHOLD_MS 500
#endif // ENABLE_NUNCHUCK

// Platform movement limits
#define MIN_PITCH -20
#define MAX_PITCH 23
#define MIN_ROLL -23
#define MAX_ROLL 20
#define MIN_YAW -69
#define MAX_YAW 69
#define MIN_SWAY -55
#define MAX_SWAY 55
#define MIN_SURGE -70
#define MAX_SURGE 55
#define MIN_HEAVE -22
#define MAX_HEAVE 25

    /**
     * @struct xy_coordf
     * @brief 2D coordinate with floating point values
     */
    typedef struct xy_coordf
    {
      float x; // -1.0 to 1.0
      float y; // -1.0 to 1.0
    } xy_coordf;

    // Default setpoint (center of platform)
    const xy_coordf DEFAULT_SETPOINT = {0, 0};

  } // namespace core
} // namespace stewy

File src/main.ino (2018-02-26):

/*
   6dof-stewduino
   Copyright (C) 2018  Philippe Desrosiers

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
   You should have received a copy of the GNU General Public License
   along with this program.  If not, see <http://www.gnu.org/licenses/>.
 */

//=== Includes
#include <Arduino.h>
#include <Servo.h>
#include "config.h"
#include "Platform.h"
#include "Logger.h"

#ifdef ENABLE_NUNCHUCK
#include "nunchuck.h"

#endif

#ifdef ENABLE_SERIAL_COMMANDS
#include "commands.h"
#endif

#ifdef ENABLE_TOUCHSCREEN
#include "touch.h"
#endif

//=== Macros
#ifdef CORE_TEENSY
//Software reset macros / MMap FOR TEENSY ONLY
#define CPU_RESTART_VAL 0x5FA0004                           // write this magic number...
#define CPU_RESTART_ADDR (uint32_t *)0xE000ED0C             // to this memory location...
#define CPU_RESTART (*CPU_RESTART_ADDR = CPU_RESTART_VAL)   // presto!

// #else
//
// #define CPU_RESTART asm volatile ("  jmp 0")                // close enough for arduino

#endif

// this is the magic trick for printf to support float
asm(".global _printf_float");
// this is the magic trick for scanf to support float
asm(".global _scanf_float");

//=== Actual code

xy_coordf setpoint = DEFAULT_SETPOINT;

Platform stu;            // Stewart platform object.

#ifdef ENABLE_SERVOS
Servo servos[6];        // servo objects.
#endif

float sp_servo[6];      // servo setpoints in degrees, between SERVO_MIN_ANGLE and SERVO_MAX_ANGLE.
// Logger* logger = Logger::instance();

float _toUs(int value) {
  return map(value, SERVO_MIN_ANGLE, SERVO_MAX_ANGLE, SERVO_MIN_US, SERVO_MAX_US);
}

float _toAngle(float value) {
  return map(value, SERVO_MIN_US, SERVO_MAX_US, SERVO_MIN_ANGLE, SERVO_MAX_ANGLE);
}

//Set servo values to the angles represented by the setpoints in sp_servo[].
//DOES: Apply trim values.
//DOES: Automatically reverse signal for reversed servos.
//DOES: Write signals to the physical servos.
void updateServos() {
  static float sValues[6];

  for (int i = 0; i < 6; i++) {
    //sp_servo holds a value between SERVO_MIN_ANGLE and SERVO_MAX_ANGLE.
    //apply reverse.
    float val = sp_servo[i];
    if (SERVO_REVERSE[i]) {
      val = SERVO_MIN_ANGLE + (SERVO_MAX_ANGLE - val);
    }

    //translate angle to pulse width
    val = _toUs(val);

    if (val != sValues[i]) {
      //don't write to the servo if you don't have to.
      sValues[i] = val;
      Logger::trace("SRV: s%d = %.2f + %d (value + trim)", i, val, SERVO_TRIM[i]);

#ifdef ENABLE_SERVOS
      servos[i].writeMicroseconds((int)constrain(val + SERVO_TRIM[i], SERVO_MIN_US, SERVO_MAX_US));
#endif
    }
  }
}

// Calculates and assigns values to sp_servo.
// DOES: Ignore out-of-range values. These will generate a warning on the serial monitor.
// DOES NOT: Apply servo trim values.
// DOES NOT: Automatically reverse signal for reversed servos.
// DOES NOT: digitally write a signal to any servo. Writing is done in updateServos();
void setServo(int i, int angle) {
  int val = angle;
  if (val >= SERVO_MIN_ANGLE && val <= SERVO_MAX_ANGLE) {
    sp_servo[i] = val;
    Logger::trace("setServo %d - %.2f degrees", i, sp_servo[i]);
  } else {
    Logger::warn("setServo: Invalid value '%.2f' specified for servo #%d. Valid range is %d to %d degrees.", val, i, SERVO_MIN_ANGLE, SERVO_MAX_ANGLE);
  }
}

void setServoMicros(int i, int micros) {
  int val = micros;
  if (val >= SERVO_MIN_US && val <= SERVO_MAX_US) {
    sp_servo[i] = _toAngle(val);
    Logger::trace("setServoMicros %d - %.2f us", i, val);
  } else {
    Logger::warn("setServoMicros: Invalid value '%.2f' specified for servo #%d. Valid range is %d to %d us.", val, i, SERVO_MIN_US, SERVO_MAX_US);
  }
}

void setupTouchscreen() {
  #ifdef ENABLE_TOUCHSCREEN
  Logger::debug("Touchscreen ENABLED.");
  rollPID.SetSampleTime(ROLL_PID_SAMPLE_TIME);
  pitchPID.SetSampleTime(PITCH_PID_SAMPLE_TIME);
  rollPID.SetOutputLimits(ROLL_PID_LIMIT_MIN, ROLL_PID_LIMIT_MAX);
  pitchPID.SetOutputLimits(PITCH_PID_LIMIT_MIN, PITCH_PID_LIMIT_MAX);
  rollPID.SetMode(AUTOMATIC);
  pitchPID.SetMode(AUTOMATIC);
  #else
  Logger::debug("Touchscreen DISABLED.");
  #endif
}

void setupPlatform() {
  stu.home(sp_servo); // set platform to "home" position (flat, centered).
  updateServos();
  delay(300);
}

//Initialize servo interface, sweep all six servos from MIN to MAX, to MID, to ensure they're all physically working.
void setupServos() {
#ifdef ENABLE_SERVOS
  int d=500;
#else
  int d=0;
#endif

  for (int i = 0; i < 6; i++) {
#ifdef ENABLE_SERVOS
    servos[i].attach(SERVO_PINS[i]);
#endif
    setServo(i, SERVO_MIN_ANGLE);
  }
  updateServos();
  delay(d);

  for(int pos=SERVO_MIN_ANGLE;pos<SERVO_MID_ANGLE;pos+=4){
    for (int i = 0; i < 6; i++) {
      setServo(i,pos);
    }
    updateServos();
    delay(10);
  }

  // for (int i = 0; i < 6; i++) {
  //   setServo(i, SERVO_MAX_ANGLE);
  // }
  // updateServos();
  // delay(d);
  //
  // for (int i = 0; i < 6; i++) {
  //   setServo(i, SERVO_MID_ANGLE);
  // }
  // updateServos();
  // delay(d);
}

/**
Setup serial port and add commands.
*/
void setupCommandLine(int bps=9600) {
  Serial.begin(bps);
  delay(50);

  Logger::info("Studuino, v1");
  Logger::info("Built %s, %s",__DATE__, __TIME__);
  Logger::info("=======================");

  #ifdef ENABLE_SERIAL_COMMANDS
  Logger::debug("Command-line is ENABLED.");

  shell_init(shell_reader, shell_writer, 0);

  const int c1 = sizeof(commands);
  if(c1 > 0) {
    const int c2 = sizeof(commands[0]);
    const int ccount = c1 / c2;

    for (int i = 0; i < ccount; i++) {
      Logger::debug("Registering command: %s",commands[i].shell_command_string);
      shell_register(commands[i].shell_program, commands[i].shell_command_string);
    }
  }
  #else

  Logger::debug("Command-line is DISABLED.");

  #endif
  delay(100);
}

void setupNunchuck() {
  #ifdef ENABLE_NUNCHUCK
  Logger::debug("Nunchuck support is ENABLED.");

  nc.begin();
  #else
  Logger::debug("Nunchuck support is DISABLED.");
  #endif
}

void setup() {
  Logger::level = LOG_LEVEL;    //config.h

  pinMode(LED_BUILTIN, OUTPUT); //power indicator
  digitalWrite(LED_BUILTIN, HIGH);

  setupCommandLine(115200);

  setupNunchuck();

  setupPlatform();

  setupTouchscreen();

  setupServos();  //Servos come last, because this setup takes the most time...
}

void loop() {

#ifdef ENABLE_SERIAL_COMMANDS
  processCommands();  //process any incoming serial commands.
#endif

#ifdef ENABLE_NUNCHUCK
  processNunchuck();
  blinker.loop();
#endif

#ifdef ENABLE_TOUCHSCREEN
  processTouchscreen();
#endif

  updateServos();   //Servos come last, because they take the most time.
}

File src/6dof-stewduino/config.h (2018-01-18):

/*
  6dof-stewduino
  Copyright (C) 2018  Philippe Desrosiers

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
  You should have received a copy of the GNU General Public License
  along with this program.  If not, see <http://www.gnu.org/licenses/>.
*/

/*
  Shamelessly stolen from the work of Daniel Waters, https://www.youtube.com/watch?v=1jrP3_1ML9M
*/

#include <math.h>
#include "Arduino.h"

#ifndef CONFIG_H
#define CONFIG_H

#define ENABLE_SERIAL_COMMANDS    //Comment out, to omit Command shell code.
#define ENABLE_NUNCHUCK           //Comment out, to omit Nunchuck code.
#define ENABLE_TOUCHSCREEN        //Comment out, to omit Touchscreen code.

//macros
#define THETA_P_DEG     45.25     //Platform joint angle (degrees) offset from AXIS[1|2|3]. A value of zero puts these joints directly on the axes
#define THETA_B_DEG     24.5      //Base Servo pinion angle (degrees) offset from AXIS[1|2|3]. A value of zero puts the servo pinion directly on the axes
#define P_RAD           50        //Platform radius (mm). The distance from the center of the platform to the center of one platform / pushrod "joint". This should be the same for all six pushrods.
#define B_RAD           80.2      //Base radius (mm). Distance from the center of the base plate to the center of one servo pinion gear. Again, this should be the same for all six servos.
#define ARM_LENGTH      25        //Servo arm length (mm). Distance from the center of the servo pivot to the center of the pushrod pivot on the servo arm.
#define ROD_LENGTH      155       //Push rod length (mm). Distance between pushrod ball joints (servo to platform).
#define Z_HOME          148       //Default Z height of the platform (above the base), with servo arms horizontal. Formally, the distance from the plane described by the collection of servo pinion gear centers, to the plane described by the collection of platform / pushrod joints.

//constants

/*
  There are three axes of symmetry (AXIS1, AXIS2, AXIS3). Looking down on the
  platform from above (along the Y axis), with 0 degrees being the X-positive line, and traveling
  in a CC direction, these are at 30 degrees, 120 degrees, and 240 degrees. All
  the polar coordinates of pivot points, servo centers, etc. are calculated based on
  an axis, and an offset angle (positive or negative theta) from the axis.
*/
const double AXIS1 =      M_PI / 6;  //30 degrees.
const double AXIS2 =      -M_PI / 2; //-90 degrees.
//AXIS 3 is just a reflected AXIS1, so we account for it in calculations.

/*
   Absolute angle that the servo arm plane of rotation is at (degrees), from the world-X axis.
*/
const double THETA_S_DEG[6] = {
  -60,
  120,
  180,
  0,
  60,
  -120
};

//Which servos are reversed. 1 = reversed, 0 = normal.
const int SERVO_REVERSE[6] = {0, 1, 0, 1, 0, 1};

const int SERVO_MIN_ANGLE = 0;
const int SERVO_MAX_ANGLE = 360;
const int SERVO_MID_ANGLE = SERVO_MIN_ANGLE + (SERVO_MAX_ANGLE - SERVO_MIN_ANGLE) / 2;
const int SERVO_MIN_US = 755;
const int SERVO_MAX_US = 2250;
//const int SERVO_MID_US=1500;
const int SERVO_MAX_DELAY = 500;  //milliseconds to transit from min to max. for HS-5625MG, this is 0.14 sec/60deg, or probably about 420ms. 500 to be safe.

const int SERVO_TRIM[] = {  //trim values, AFTER reversing
  0,
  20,
  0,
  135,
  0,
  120
};

#endif

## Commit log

2018-01-09 Initial commit
    Initial commit. Adding libraries for Wii nunchuk, Stewart platform math. Adding documentation. Updated README with project description.
    [StewartPlatformSimulator_v2.xlsm]
2018-01-18 Updated CAD designs, added DXF files
    Fixed some small design flaws, added mounting holes for Chucky, moved standoffs to allow easier battery entry, created DXF versions.
    [base_bottom.dxf, base_top.dxf, platform_large.dxf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]
2018-01-18 updates to documentation
    Updated README, block diagram for wiring, added datasheets for 4-wire Touchscreen parts
    [StewartPlatformSimulator_v2.xlsm, stewduino.sch]
2018-01-18 Add support for command shell, IK model, framework for nunchuck and touchscreen
    Implement servo control and integraiton with Stewart platform IK model. Added skeleton code for Nunchuck control and Touchscreen. Some code cleanup.
2018-01-19 Renamed .hpp files back to .h, since that was dumb. also renamed .ino files to .cpp, so we can migrate to PlatformIO / Atom.
    Migrated to PlatformIO / Atom. So of course everything is broken and no
    longer builds.
    [6dof-stewduino.cpp, config.h, nunchuck.cpp]
2018-01-19 Changes to folder structure, in the blind hope that something will make PlatformIO work properly. No dice. Still broken.
    [6dof-stewduino.cpp, Stewart.cpp, config.h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]
2018-01-19 Restructure of doc tree
    [base_bottom.dxf, base_top.dxf, platform_large.dxf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]
2018-01-19 Switch to managed "WiiChuck" library. I say "managed", but PlatformIO of course refuses to recognize any types that are linked from this library. Yay, platformIO.
2018-01-19 Revert "Switch to managed "WiiChuck" library. I say "managed", but PlatformIO of course refuses to recognize any types that are linked from this library. Yay, platformIO."
    This reverts commit 32b2e8b2681641efdfb745aa23ce5807c7b94537.
    [nunchuck.cpp]
2018-01-22 Added basic logging framework (to remove cals to Serial.printf). Renamed all .cpp files to .ino, to PIO will build the damn thing.
2018-01-22 Added Excel BOM
    [BOM.xlsx]
2018-01-23 Fixed logging.
    [BOM.xlsx]
2018-01-23 Added magical support for floating point printf in PIO.
2018-01-23 Update touchscreen pin config.
2018-01-23 Make physical servos optional, so we can test other things without them.
2018-01-24 Add "mset" and "msetall" shell commands, for setting servo values in microseconds.
2018-01-24 enable setMicroSeconds command, add abstraction for servo physical pins.
2018-01-25 Support for "double-click" of nunchuck buttons.
2018-01-25 Fixed build-breaking changes in Modes enum.
    [config.h]
2018-01-25 Fix top-level WiiMote controls (mode switching, direction switching subMode switching).
    [config.h]
2018-01-25 Add support for LED blinky on mode change.
2018-01-26 Remove delay of servo init, when servos are not enabled.
2018-01-26 Changed default blink millis from 400 to 200.
2018-01-26 Removed funky UTF-8 characters that were causing problems with platformio
    [main.ino]
2018-01-27 Created asynch Blinker library, to stop blocking blinky processes. (There is still a bug where the Blinker sets the output pin to LOW when done, regardless of the original state).
    [config.h, main.ino]
2018-01-27 Added support for SQUARE mode, reordered switch statement to reflect ordering of Mode enum.
2018-01-28 Upped touchscreen VOLTAGE_SETTLE time from 20us to 100us.
2018-01-28 Fixed bug in debug output when ENABLE_SERVOS is undefined.
    [commands.ino]
2018-01-28 Inverted blinker, so LED is always on.
    [config.h]
2018-01-28 Swap YM and YP pins, tweak extents for touchscreen, added basic PID parameters (not final).
    [config.h]
2018-01-28 Added PID controller.
2018-01-28 Re-enabled servos.
2018-01-28 Change to startup servo exercise.
2018-01-29 Added shell commands for adjusting PID values.
2018-01-29 Slow down the startup / servo init.
2018-01-29 FIXED: Don't process the touchscreen input when the PID controller is in MANUAL mode.
2018-01-29 FIXED: changing PI values via command-line has no effect.
    [commands.ino]
2018-01-30 Make better use of built-in Arduino math functions (map() and constrain()).
2018-01-30 FIXED: Stewduino wiring diagram / schematic shows Touchscreen connections on wrong analog pins.
    [stewduino.sch]
2018-01-30 Fixed PID controller parameters (min, max), and abstracted parameters out to #defines in config.h
    [config.h, main.ino]
2025-06-03 Optimize inverse kinematics algorithm with early exits, pre-computed values, and improved numerical stability
    [Platform.cpp]
2025-06-03 Add Touchscreen calibration
2025-06-03 Fix Shell type error by properly handling C/C++ interoperability with forward declarations
    [CommandLine.cpp]
2025-06-03 Fixed TouchScreenDriver::getPID build issues
    [TouchScreen.cpp]
2025-06-03 Fix Shell type error by using C-style function calls instead of C++ wrapper
    [CommandLine.cpp]
2025-06-03 Fix uninitialized variable warning in TouchScreenDriver::getPID by initializing pid to nullptr and handling invalid axis case
    [TouchScreen.cpp]
2025-06-03 Enable Servos
2025-06-03 Fix Blinker implementation by using a global instance and calling loop() in main loop
    [Nunchuck.cpp, main.cpp]
2025-06-03 improvements to PID default values and initialization. use log.info() instead of log.notice()
2025-06-04 Add proper destructors to clean up dynamically allocated objects and prevent memory leaks
    [Nunchuck.cpp, Platform.h, TouchScreen.cpp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]
2025-06-04 Add acceleration to servos, for smoother movement.

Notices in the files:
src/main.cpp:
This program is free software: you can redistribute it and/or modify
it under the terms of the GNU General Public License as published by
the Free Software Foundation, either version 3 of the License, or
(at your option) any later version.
